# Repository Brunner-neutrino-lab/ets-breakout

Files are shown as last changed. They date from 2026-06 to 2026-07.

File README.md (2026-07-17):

# ETS per-channel SiPM breakout boards

Passive break-out boards that replace the (broken) **`iv-pulse-mux`** board in the
Brunner-lab **ETS-96-channel-IV-pulse-mux** system. Instead of relay-multiplexing 24
channels onto one shared sense line, each breakout board brings **every channel out to
its own coaxial jack** so channels can be biased/measured individually with external
instruments.

> Note: the public GitHub repo `IV-MUX-public` is a *different, older* board (15
> ch/board relay mux). The authoritative source is the read-only upstream snapshot
> under [`reference/ETS-96-channel-IV-pulse-mux/`](reference/) (`iv-pulse-mux`,
> connector **J5**) — see [`reference/UPSTREAM.md`](reference/UPSTREAM.md).

## What each board does

- Mates the detector-side connector **`QSE-040-01-L-D-A`** (J5) — same socket the
  `iv-pulse-mux` board used, mating the existing QTE-040 header upstream. **J5 sits on
  the back face (B.Cu)**, opposite the jacks: the detector plugs into the back, cables
  come off the front.
- Fans **25 signals → 25 coax jacks**: `SIPM_K0…K23` (24) + `IV` (1).
  `IV` is bussed on QSE pins 40 & 42 → one jack. `THERM4/THERM5` are **not** broken out.
  The detector socket keeps designator **J5** (upstream mapping); the jacks are **J6…J30**
  (K0→J6 … K23→J29, IV→J30), and each jack carries its channel identity (`K0…K23`, `IV`) as a
  **silkscreen label**. Mounting-hole designators (MH…) are hidden on silk.
- `GNDA` (52 signal-row pins + 8 G-pads) forms the ground/shield; a **guard ring** per
  channel tied to `GNDA`. No bias-tee / ESD diode / DC block.

### Variants
| Board | Jacks |
|---|---|
| **A** | 25 × MCX (straight, vertical through-hole) |
| **B** | 25 × SMA |
| **C** | 25 × U.FL |
| **D** | 25 × SMP (vertical SMT, SMP-MSLD-PCS-20) |

One board services one QSE-040 (25 ch). The full 96-channel system uses **4 boards**;
all four connectors share the identical J5 pinout, so a single layout works in every
position.

## Design decisions (2026-06-16)

| Aspect | Decision |
|---|---|
| Mechanical | **Free-form standalone** — only the QSE-040 must mate; fresh outline + mounting, no size constraint |
| J5 mounting face | **Back (B.Cu)** — detector mates on the back, all coax jacks on the front |
| Jack mounting | **Edge / right-angle** — jacks at board edges, cables exit sideways |
| Signal integrity | **Controlled 50 Ω, 4-layer** (L1 sig / L2 GND / L3 GND / L4 sig) |
| Guard | Guard ring per channel → `GNDA` |

## Pinout = single source of truth

[`pinout.py`](pinout.py) holds the authoritative QSE-040 (J5) pin→net map, derived from
the upstream schematic netlist (`kicad-cli sch export netlist`), **not** hand-transcribed
from a screenshot. The generator imports it; never hand-place a channel. Re-export and
regenerate if the upstream board changes.

```
python pinout.py             # dump signal -> QSE pin map
python tests/test_pinout.py  # sanity + self-consistency checks
```

## Build pipeline

All `tools/*.py` run under KiCad's bundled interpreter
(`"C:/Program Files/KiCad/10.0/bin/python.exe"`).

```
# Board A (MCX, through-hole) — FreeRouting autoroute, ZERO signal vias:
tools/gen_board.py mcx                 # placement + nets + outline + holes (balanced ~12/13 split; SPLIT="planar" = old 8/16)
tools/finalize_board.py <pcb> setup    # 4-layer stackup + GND zones (no routes yet)
tools/export_dsn.py <pcb> B.Cu         # write Specctra .dsn for the router
#   -> FreeRouting v2.2.4 (java) autoroute -> .ses
tools/import_ses.py <pcb>              # pull the routed B.Cu tracks back in
tools/finalize_board.py <pcb> stitch   # GND stitching vias
tools/fill_zones.py <pcb>              # fill GND pours (separate pass)
tools/tie_islands.py <pcb>             # island-tie vias
kicad-cli pcb drc <pcb>                # verify (0 violations, 0 unconnected)

# Boards B/C/D (SMA/U.FL/SMP) — deterministic router, single finalize pass:
tools/gen_board.py [sma|ufl|smp]
tools/finalize_board.py <pcb>          # stackup + 50 ohm routes + GND zones + stitching (one pass)
tools/fill_zones.py <pcb>
kicad-cli pcb drc <pcb>

kicad-cli pcb export gerbers|drill|pos ... ; tools/make_bom.py <pcb> <csv>   # fab outputs
```

**Board A** routes as a **balanced ~12/13 planar fan on B.Cu** (engineer-reviewed). The 25
jacks are split 12 on the west edge / 13 on the east and **ordered by their QSE pin** so every
native channel escapes as a **straight line**: west = K8–K15 (native) + K16,K17 (wrapping the
top corner) + K6,K7 (wrapping the bottom corner); east = K18–K23, IV, K0–K5. The 4 spilled
channels **wrap around the connector ends on B.Cu** (2 per corner), so the fan stays **all-B.Cu
with zero connector crossings and zero signal vias** (the through-hole MCX signal pin is plated
through every layer, so the B.Cu escape lands on it with no face-change via). FreeRouting does
the autoroute; only GND stitching + island-tie vias remain. Balancing shrank the board 32 mm
(75 × 157 → **75.0 × 125.2 mm**). The old lopsided 8/16 fan is retained as the `gen_board`
`SPLIT="planar"` option; `SPLIT="balanced"` is the default. **Boards B/C/D** still use the
deterministic router — escape past the QSE pads → one straight diagonal to the jack → straight
into the signal pad between grounds — with a 12/12 split (the `SPLIT="balanced"` flag) that
crosses 4 channels on the bottom layer. Vertical jacks (U.FL, MCX, SMP) are auto-rotated so
their signal pad faces the QSE.

## Status

**All four boards route DRC-clean (0 violations, 0 unconnected)** at the 50 Ω trace
width on the JLCPCB **JLC04161H-7628** 4-layer 1.6 mm stackup. Board A carries **0 signal
vias** (GND stitching + island-tie vias only; all 25 nets on B.Cu).

| Board | Connector | Size | Fab package |
|---|---|---|---|
| A | MCX straight, through-hole (MCX-J-P-H-ST-TH1) | 75.0 × 125.2 mm | `boards/board-A-mcx/board-A-mcx-fab.zip` |
| B | SMA (901-143-6RFX) | 75 × 149 mm | `boards/board-B-sma/board-B-sma-fab.zip` |
| C | U.FL (U.FL-R-SMT-1) | 70 × 99 mm | `boards/board-C-ufl/board-C-ufl-fab.zip` |
| D | SMP (SMP-MSLD-PCS-20) | 75 × 120 mm | `boards/board-D-smp/board-D-smp-fab.zip` |

Each fab zip = gerbers (4 copper + mask/silk/edge) + Excellon drill + position CSV + BOM CSV.

**Assembly:** the default build is **fab-only + hand-solder** (exact Samtec parts from
DigiKey). An optional **JLCPCB assembled build is possible** as a mixed SMT (QSE) + THT (MCX)
job using LCSC parts: QSE-040 = **C3652741** (exact Samtec, plain -A), MCX = **C5137197**
(BAT Wireless `BWMCX-KE`, a generic 50 Ω THT MCX jack; alt **C49118404**). Both are JLC-library
*Extended* parts and the 25 THT MCX jacks need JLC's through-hole/wave-solder assembly add-on.
**Gate before an assembled order:** confirm the `BWMCX-KE` land pattern matches our footprint
(centre signal + 4 grounds on 5.08 mm, drills 1.10/1.40) — it's a generic equivalent, not
dimensionally verified. The fab BOM (`make_bom.py`) carries these in an **LCSC column**. Fab is
**JLCPCB only**.

**Impedance:** channel traces are **0.325 mm** wide (unchanged) ≈ 50 Ω single-ended microstrip
on the JLCPCB **JLC04161H-7628** 4-layer 1.6 mm stack (0.2104 mm 7628 prepreg to the adjacent
inner GND plane, Dk ≈ 4.4), GND pour held back 0.30 mm to limit coplanar coupling. 0.325 mm is
JLC's own published 50 Ω single-ended width for JLC04161H-7628; the full derivation (JLCPCB
calculator RS_50 = 0.3244 mm + KiCad TransLine / IPC-2141 microstrip, every input stated) is in
[`docs/impedance.md`](docs/impedance.md). **Order as controlled impedance** (JLC's
impedance-control option on that stackup) so JLC re-tunes the etched width to their exact stackup.

**Footprints — all datasheet-verified:** MCX `Samtec_MCX-J-P-H-ST-TH1` (straight, vertical
**through-hole** jack) matches the Samtec drawing (`docs/datasheets/`, mcx-j-p-x-st-th1-mkt):
pad 1 signal drill Ø1.10 mm centered + 4× ground drill Ø1.40 mm on a 5.08 mm square. SMA and
U.FL from the KiCad library; QSE-040 from the ETS repo; SMP `SMP_Amphenol_SMP-MSLD-PCS-20`
(Amphenol RF, vertical SMT) is the SnapMagic land pattern (pad `G` renamed to `2`), signal on
an external tab.

**3D models:** QSE-040 and SMP have local STEP models in [`models/`](models/); U.FL uses
KiCad's bundled model. SMA and the through-hole MCX have no 3D model yet (gap). Models are
visual only — fab is unaffected.

**Before committing to fab:**
- Boards are built directly from `pinout.py` (no netlist-driven flow). A **reference
  schematic for human review** is in [`docs/schematic/`](docs/schematic/) (PDF + `.kicad_sch`),
  generated from the same `pinout.py` by `tools/gen_schematic.py` — its exported netlist is
  verified identical to the pin map.
- ~~Confirm the straight-MCX orderable MPN~~ **Confirmed 2026-07-15:** Board A is now
  **through-hole** — `MCX-J-P-H-ST-TH1` (DigiKey SAM8944-ND). Purchase package in [`order/`](order/).

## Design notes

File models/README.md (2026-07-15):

# 3D models

STEP models referenced by the footprints in [`../lib/ets-breakout.pretty/`](../lib/ets-breakout.pretty/).
Footprints reference these via `${KIPRJMOD}/../../models/<file>` — `KIPRJMOD` resolves
to each board's directory (`boards/board-*/`), so `../../models/` lands here regardless
of which board is open.

| Part | File | Source | Status |
|---|---|---|---|
| QSE-040-01-L-D-A (J5) | `QSE-040-01-L-D-A.stp` | upstream `reference/` snapshot | **present** |
| MCX-J-P-H-ST-TH1 (Board A, THT) | — | — | **gap** (need vertical through-hole model; the SMD `MCX-J-P-X-ST-SM1.step` no longer matches Board A's through-hole part) |
| SMP-MSLD-PCS-20 (Board D) | `SMP-MSLD-PCS-20.stp` | Amphenol / SnapMagic | **present** |
| U.FL-R-SMT-1 (Board C) | `U.FL_Hirose_U.FL-R-SMT-1_Vertical.step` | KiCad bundled lib (copied local) | **present** |
| SMA 901-143-6RFX (Board B) | — | — | **gap** (vendor-gated) |

Two footprints lack a local resolving model — **Board A MCX THT** and **SMA**.

- **MCX-J-P-H-ST-TH1** (Board A): Board A moved from the SMD MCX to the through-hole
  `MCX-J-P-H-ST-TH1`. The old `MCX-J-P-X-ST-SM1.step` is the SMD variant and no longer matches
  the through-hole part, so no model resolves for the `Samtec_MCX-J-P-H-ST-TH1` footprint. To
  fill it, source a vertical THT MCX STEP, drop it here, and add a
  `(model "${KIPRJMOD}/../../models/<file>")` line to
  `lib/ets-breakout.pretty/Samtec_MCX-J-P-H-ST-TH1.kicad_mod`.
- **SMA** (Board B): the SMA STEP is behind a vendor login (Amphenol RF / SnapMagic / Ultra
  Librarian); its footprint carries no `(model …)` line. To fill it, drop the vendor STEP here
  as `SMA_Amphenol_901-143-6RFX.stp` and add a
  `(model "${KIPRJMOD}/../../models/SMA_Amphenol_901-143-6RFX.stp")` line to
  `lib/ets-breakout.pretty/SMA_Amphenol_901-143_Horizontal.kicad_mod`, then regenerate Board B.

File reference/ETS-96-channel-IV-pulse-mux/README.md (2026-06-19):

# ETS 96-Channel IV-Pulse Multiplexer

**Organization:** McGill University Physics – Electronic Design Support Group  
**Designer:** Eamon Egan  
**Schematic Date:** 2019-11-12 (Rev 1.0)  
**Design Tool:** KiCad 9.0  

---

## Overview

This repository contains the complete design files for a **96-channel I-V curve pulse multiplexer** used in detector physics instrumentation. The system routes bias voltage and sense signals to one of 96 detector channels (e.g., SiPMs or similar devices) under Arduino microcontroller command, enabling automated current-voltage (I-V) characterization of large detector arrays.

The system is organized as:
- **Four 24-channel Mux boards** (`iv-pulse-mux`) — each handling 24 detector channels via reed relays and shift registers.
- **One Motherboard** (`iv-pulse-motherboard`) — orchestrating all four mux boards, distributing power, and providing the interface to the control system.
- **Arduino firmware** (`Arduino code/iv-mux/iv-mux.ino`) — running on an Arduino Nano Every (ATmega4809), accepting serial commands to switch channels, read temperature, and control auxiliary lines.

---

## Repository Layout

```
.
├── README.md                          ← This file
├── docs/                              ← Project documentation
│   ├── architecture.md                ← System-level design overview
│   ├── hardware/
│   │   ├── iv-pulse-mux-board.md      ← IV Pulse Mux PCB documentation
│   │   ├── motherboard.md             ← Motherboard documentation
│   │   ├── component-libraries.md     ← Custom schematic and footprint libraries
│   │   └── pcb-design-rules.md        ← Net classes and PCB design rules
│   ├── firmware/
│   │   ├── firmware-overview.md       ← Arduino firmware architecture
│   │   └── serial-commands.md         ← Serial command protocol reference
│   ├── fabrication/
│   │   └── fabrication-guide.md       ← Fabrication and assembly guide
│   └── operation/
│       └── user-guide.md              ← System operation and integration guide
│
├── Arduino code/iv-mux/iv-mux.ino    ← Microcontroller firmware
│
├── iv-pulse-mux.kicad_pro             ← KiCad project: IV Pulse Mux board
├── iv-pulse-mux.kicad_sch             ← Root schematic (IV Pulse Mux)
├── iv-pulse-mux.kicad_pcb             ← PCB layout (IV Pulse Mux)
│
├── iv-pulse-motherboard.kicad_pro     ← KiCad project: Motherboard
├── iv-pulse-motherboard.kicad_sch     ← Root schematic (Motherboard)
├── iv-pulse-motherboard.kicad_pcb     ← PCB layout (Motherboard)
│
├── Channels.kicad_sch                 ← Hierarchical sheet: 24 channel cells
├── sense-relay.kicad_sch              ← Hierarchical sheet: single sense relay cell
├── sense-relays.kicad_sch             ← Hierarchical sheet: sense relay group
├── bias-relay.kicad_sch               ← Hierarchical sheet: single bias relay cell
├── bias-relays-with-control.kicad_sch ← Hierarchical sheet: bias relay group
├── control.kicad_sch                  ← Hierarchical sheet: shift register control
├── muxboard-interface.kicad_sch       ← Hierarchical sheet: board connector interface
│
├── iv-mux.pretty/                     ← Custom PCB footprint library
├── samtec-footprints.pretty/          ← Samtec QSE connector footprints
├── passthrough.pretty/                ← Panel passthrough connector footprints
├── bias-switches-symlibs/             ← Custom schematic symbol library
│
├── fab-files.kicad_jobset             ← Automated fabrication output job set
├── fabrication-toolkit-options.json   ← Gerber export settings
├── fp-lib-table                       ← KiCad footprint library table
├── sym-lib-table                      ← KiCad symbol library table
└── mcgill-university-2.*              ← McGill University logo (SVG/DXF/PNG)
```

---

## Quick-Start

### Hardware

1. Order PCBs and assemble using the [Fabrication Guide](docs/fabrication/fabrication-guide.md).
2. Stack up to four Mux boards on the Motherboard via the Samtec QSE-040 connectors.
3. Connect detector channels to MCX connectors on the Mux boards.
4. Apply bias supply and sense lines via the Motherboard.

### Firmware

1. Open `Arduino code/iv-mux/iv-mux.ino` in the Arduino IDE.
2. Ensure `#define IVPULSEMUX` is present (enabled by default).
3. Select board: **Arduino Mega or Mega 2560** (required for ATmega4809 / Nano Every with Mega2560 profile).
4. Upload to the Arduino Nano Every.
5. Open a serial terminal at **9600 baud**.
6. Type a blank line to print the command help.

For a full command reference, see the [Serial Commands Reference](docs/firmware/serial-commands.md).

---

## Documentation Index

| Document | Description |
|---|---|
| [System Architecture](docs/architecture.md) | Top-level design intent, block diagram, and signal flow |
| [IV Pulse Mux Board](docs/hardware/iv-pulse-mux-board.md) | Schematic, PCB, and component details for the 24-channel mux board |
| [Motherboard](docs/hardware/motherboard.md) | Schematic and PCB details for the control motherboard |
| [Component Libraries](docs/hardware/component-libraries.md) | Custom schematic symbols and PCB footprints |
| [PCB Design Rules](docs/hardware/pcb-design-rules.md) | Net classes, clearances, and trace width rules |
| [Firmware Overview](docs/firmware/firmware-overview.md) | Arduino firmware architecture and state machine |
| [Serial Commands](docs/firmware/serial-commands.md) | Complete serial command protocol reference |
| [Fabrication Guide](docs/fabrication/fabrication-guide.md) | PCB fab, BOM, and assembly instructions |
| [User / Operation Guide](docs/operation/user-guide.md) | How to operate and integrate the system |

---

## Known Issues / Open Items (Rev 1.0)

- `BYPASS` signal is connected to Arduino pin 12 as a **temporary workaround**; the comment in firmware notes this should be corrected in a future revision.
- The `iv_on_pins[]` array uses analog pins `A0–A3` instead of the originally intended `THERM1–THERM4` thermistor pins — firmware comment notes this was an oversight.
- Low-power sleep mode (`LOWPOWER_SLEEP`) was prototyped but **is currently disabled**; register access issues on the ATmega4809 need to be resolved.
- The `q` (sequence) command is **only available in non-IV-pulse-mux mode** (i.e., the older 6×15 channel variant).
- Symbol library `iv-mux-rescue` references an absolute path on the designer's machine (`C:/Users/eamon/...`) and must be remapped when opening on a different workstation.

---

## Revision History

| Rev | Date | Description |
|---|---|---|
| 1.0 | 2019-11-12 | Initial release (schematic date) |

---

## License

Hardware design files are the property of McGill University Physics, Electronic Design Support Group. Contact the Brunner Neutrino Lab for use and distribution terms.

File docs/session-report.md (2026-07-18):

# Session handoff — ETS per-channel breakout boards

Report from the development session that built `ets-breakout/`. Intended for a
"manager" session reorganizing the whole working directory.

> **Historical record.** The reorganization this report recommended (§5–§6) has
> since been carried out: `ets-breakout/` is now its own standalone git repo, the
> upstream clone is a de-gitted read-only snapshot under `reference/`, and the SMP
> project is a separate sibling repo. Paths below describe the *old* layout.

> **Update 2026-06-22 — Board D (SMP) added.** A fourth variant was generated with
> the same pipeline: 25× **Amphenol SMP-MSSB-PCS** (SMP *male*, vertical SMT,
> 50 Ω DC–18 GHz), footprint carried over from the sibling SMP-feedthrough project.
> Unlike A/B/C, the SMP's center signal pad is enclosed by its ground frame on all
> four sides, so `finalize_board.py` routes the channel on B.Cu under the frame and
> enters through a **center via-in-pad** (gated on jacks whose footprint name
> contains "SMP"). Board is 74 × 112 mm, **DRC 0/0**, all 25 signal pads via-verified;
> fab package at `boards/board-D-smp/board-D-smp-fab.zip`. Fab note: order with
> plugged/capped vias (or hand-solder) so the SMT joint doesn't wick into the via.

> **Update 2026-06-22 — J5 moved to the back face (all boards).** The QSE-040 (J5)
> is now mounted on the **opposite PCB face from the coax jacks** (J5 on B.Cu, jacks
> on F.Cu): the detector plugs into the back, cables come off the front. `gen_board.py`
> flips J5 after assigning nets; the pad→net binding is preserved, so connectivity is
> unchanged. `finalize_board.py` was made face-agnostic — it detects which copper face
> J5's SMD pads are on (via `IsOnLayer`, since `GetLayer()` lies for a flipped SMD pad)
> and routes escapes on that HOME layer, hopping to the OTHER signal layer only for the
> crossing fans. All four boards re-routed and re-exported: **DRC 0/0**, J5 = bottom and
> all 25 jacks = top in the placement CSVs.

> **Update 2026-06-22 — 3D models + Board A changed to straight MCX.** 3D STEP models
> were attached: QSE-040 (from `reference/`), SMP-MSSB-PCS and the straight MCX (from the
> sibling SMP-feedthrough project) live in `models/` and are referenced via
> `${KIPRJMOD}/../../models/…`; U.FL uses KiCad's bundled model. SMA's 3D model was
> skipped. **Board A now uses a straight (vertical) surface-mount MCX jack**
> (`Samtec MCX-J-P-X-ST-SM1`, datasheet rev C) instead of the right-angle through-hole
> part — cable exits straight up, flat placement, and the signal pad routes like U.FL
> (SMD, signal reachable between the four corner grounds, no center via). The right-angle
> MCX footprint and its datasheet were removed. Boards A & B re-routed and re-exported,
> **DRC 0/0**. Straight-MCX orderable MPN (`MCX-J-P-H-ST-SM1`) is inferred — confirm.

## 1. What this session built

Three PCBs that **replace the broken `iv-pulse-mux` board** in the Brunner-lab
**ETS-96-channel-IV-pulse-mux** system with a *passive per-channel breakout*. Each
board mates the detector-side **QSE-040-01-L-D-A** socket and fans every channel out
to its own coax jack:

| Board | Jacks (25 each) | Part | Status |
|---|---|---|---|
| A | MCX × 25 | Samtec MCX-J-P-H-RA-TH1 (DK SAM10607-ND) | DRC 0/0, fab-ready |
| B | SMA × 25 | Amphenol RF 901-143-6RFX (DK ARFX1232-ND) | DRC 0/0, fab-ready |
| C | U.FL × 25 | Hirose U.FL-R-SMT-1(10) | DRC 0/0, fab-ready |

25 break-outs = 24 `SIPM_K0..K23` + `IV`. 12 K-channels bundle to flange 1 (one edge),
12 to flange 2 (other edge), IV to flange 3. 4-layer, 50 Ω microstrip on PCBWay default
4-layer stackup, GND pours all layers + stitching, 4× M3 holes. All footprints are
datasheet-verified.

**Everything is generated from one source of truth, `pinout.py`** — no hand placement.
Pipeline (KiCad 10 bundled Python):
```
gen_board.py [mcx|sma|ufl]   placement + nets + outline + holes  (imports pinout.py)
finalize_board.py <pcb>      4-layer stackup + 50Ω routes + GND zones + stitching
fill_zones.py <pcb>          fill pours (separate pass; in-memory fill segfaults)
kicad-cli pcb drc / export   verify + gerbers/drill/pos ; make_bom.py for BOM
```

## 2. Key decisions (with rationale)

- **Source repo identification.** The repo Lucas named (`ETS-96-channel-IV-pulse-mux`)
  is the right one; the public GitHub `IV-MUX-public` is a *different, older* board —
  don't conflate. The authoritative QSE-040 (J5) pin→net map was extracted from the
  upstream schematic **netlist** (`kicad-cli sch export netlist`), not eyeballed.
- **QSE-040 is carried on the new board** (same socket the mux used), mating the existing
  QTE-040 upstream. Confirmed with Lucas.
- **Flexible 12/12 channel→flange split** (Lucas's call). The connector's two pin rows
  are asymmetric (16 channels one row, 8 the other), so a 12/12 split has a hard floor of
  **4 nets crossing** the connector (routed on the bottom layer). The generator computes
  the optimal split from pad geometry to hit that floor.
- **Routing primitive = escape + single straight diagonal + straight into pad.** Monotonic
  fans are planar this way. (Vertical-bus and nested-bus fan-outs were tried and both
  introduced crossings — diagonal is correct here.)
- **IV jack** ended up inline on one edge (a center-top position had no clean routing
  lane). Still a separate connector cabled to flange 3.
- **Trace width 0.34 mm ≈ 50 Ω** microstrip on the PCBWay default 4-layer; `EDGE_GAP`
  widened to 26 mm so the end-channel fan diagonals stay shallow enough to clear at width.
  Recommend ordering as **controlled impedance** so PCBWay tunes to their exact stackup.
- **U.FL** = low-voltage use only (rated ~60 V vs bias up to ~70 V); noted, Lucas accepted.

## 3. Status / what's verified vs assumed

- All three boards: **0 DRC violations, 0 unconnected.** Fab packages
  (`boards/board-*/...-fab.zip`) = gerbers (4 copper + mask/silk/edge) + Excellon drill +
  placement CSV + BOM CSV.
- All four footprints datasheet-verified (MCX vs Samtec drawing rev H, archived in
  `docs/datasheets/`; SMA + U.FL from KiCad lib; QSE-040 from the ETS repo).
- **Open items (housekeeping, not blocking):** (a) no schematic/netlist — boards are built
  directly from `pinout.py`, which is unconventional; (b) MCX signal pin assumed centered
  in the ground square (drawing shows no offset); (c) impedance is nominal — confirm with
  PCBWay's stackup; (d) the `MCX-J-P-H-RA-TH1` 3D model isn't attached (cosmetic).

## 4. `ets-breakout/` layout (clean, self-contained)

```
ets-breakout/
  pinout.py                      SINGLE SOURCE OF TRUTH (QSE-040 J5 pin->net, breakout list)
  tests/test_pinout.py           sanity + self-consistency checks
  tools/  gen_board.py finalize_board.py fill_zones.py make_bom.py
  lib/ets-breakout.pretty/       4 verified footprints (QSE-040, MCX, SMA, U.FL)
  docs/datasheets/               Samtec MCX drawing rev H
  boards/board-{A-mcx,B-sma,C-ufl}/   .kicad_pcb/.kicad_pro + renders + *-fab.zip
  README.md                      full pipeline + status
```

## 5. The directory problem the manager should fix

The working dir currently mixes **three unrelated things** at the top level:

1. **The original SMP-feedthrough project** (different deliverable): `CLAUDE.md`,
   `smp-adapter-boards-brief.md`, `README.md`, `boards/`, `geometry/`, `lib/`, `tools/`,
   `tests/`, `docs/`, `models/`, `out/`, `MCX/`, and stray top-level reports
   (`board-A-mcx-drc.rpt`, `board-B-ufl-*.rpt/json`, `board-A-mcx-erc.rpt`).
2. **A clone of the upstream reference repo** `ETS-96-channel-IV-pulse-mux/` — **has its
   own nested `.git`** (messy inside the parent repo). It was the source of the pinout.
3. **This session's project** `ets-breakout/` (self-contained).

⚠️ **Name collision:** the SMP project's boards are *also* named `board-A-mcx` and
`board-B-ufl`; this project has `board-A-mcx`, `board-B-sma`, `board-C-ufl`. Two different
"board-A-mcx" exist. Keep them namespaced by project directory.

Other cruft to clean: `ets-breakout/__pycache__/`, `ets-breakout/board-*-drc.rpt` (kicad-cli
dumps to CWD), redundant renders in `board-A-mcx/` (`placement-A.svg`, `routed-A-*.pdf`,
keep `routed-top.pdf`). No `.gitignore` in `ets-breakout/`.

## 6. Recommended organization

- **Separate the two board projects into top-level directories** (or two repos):
  `smp-feedthrough/` (the original) and `ets-breakout/` (this one). They share *nothing*
  functionally and the name collision alone justifies the split. `ets-breakout/` is
  already self-contained and can move as-is.
- **The upstream `ETS-96-channel-IV-pulse-mux/` clone:** the data we needed is already
  captured (`ets-breakout/pinout.py` + archived datasheet). Recommend **removing its
  nested `.git`** and keeping it under `reference/` (read-only) *or* dropping it entirely
  and recording the upstream URL + commit in a README. Do **not** leave a nested git repo.
- **Add `.gitignore`** for `__pycache__/`, `*.kicad_prl`, stray `*-drc.rpt/json`,
  `out/`, and (decide) the generated `fab/` + renders since they regenerate from the tools.
- **Keep `ets-breakout/` as-is internally** — it follows the SMP project's own conventions
  (single-source-of-truth generator, local datasheet-verified footprints, test + DRC gate).
- Consider a **top-level README** that names the projects and points into each.

If the manager wants the boards rebuilt from scratch to confirm reproducibility:
`for v in mcx sma ufl: gen_board.py $v -> finalize_board.py -> fill_zones.py -> drc`.

> **Update 2026-06-24 — Board D SMP changed to SMP-MSLD-PCS-20.** Swapped the
> SMP-MSSB-PCS (enclosed centre pad) for **Amphenol RF SMP-MSLD-PCS-20** (vertical SMT,
> 4.08 mm max height), imported from the user-supplied SnapMagic footprint/symbol/STEP
> (pad `G` renamed `2`). Its signal is an **external tab** on one side of the body, so the
> centre via-in-pad scheme is gone — it routes like the other flat SMD jacks. `_edge` now
> rotates every flat jack so its signal pad faces the QSE, derived from the actual pad
> geometry (U.FL -X edge, SMP-MSLD +Y tab, MCX centred), replacing the hard-coded U.FL
> rotation; `finalize_board.py` dropped the SMP centre-via branch. Board D is 75 x 120 mm,
> **DRC 0/0**, all 25 tabs verified facing inward; all four boards re-checked 0/0.

> **Update 2026-07-11 — Board A finalized for purchase (MCX MPN confirmed, full order BOM).**
> The one open sourcing item is closed: **`MCX-J-P-H-ST-SM1` is the exact orderable straight-SMT
> MCX** (verified against the Samtec SM1 rev C drawing — now in `docs/datasheets/` as
> `Samtec_MCX-J-P-X-ST-SM1.pdf`; the previously-bundled `…ST-MT1.pdf` was the through-hole
> variant — and the live DigiKey listing **SAM10608-ND**, 4,577 in stock, $3.99 @ 100).
> QSE-040 socket confirmed as DigiKey **SAM8124-ND** ($7.27, 2,021 stk; plain suffix only —
> `-RT1` needs retention holes the board lacks). `make_bom.py` PARTS now carries both DK PNs;
> all four board BOM CSVs + fab zips regenerated. Board A re-verified: **0 DRC errors /
> 0 unconnected** (25 warning-level 0.7 mm silk text-height notes only, cosmetic).
> Controlled-impedance fab quotes pulled live: JLCPCB ~$65 HASL / ~$83 ENIG qty 5
> (JLC04161H-7628 stackup, ±5 Ω at 50 Ω, their 50 Ω width ≈0.35 mm vs our 0.34 mm nominal);
> PCBWay ~$122/$148. Full order table + DigiKey quick-add in `docs/BOM.md` §Purchase order.
> **System order ≈ $560–590** (110× MCX + 5× QSE + 5 PCBs, ENIG).

> **Update 2026-07-11 — MCX datasheet cleanup (MT1 drawing removed).** Re-verified
> `docs/datasheets/Samtec_MCX-J-P-X-ST-SM1.pdf` byte-identical (SHA-256) to the live
> Samtec print (`suddendocs.samtec.com/prints/mcx-j-p-x-st-sm1-mkt.pdf`); its text confirms
> *MCX STRAIGHT, SMT JACK – 50 OHM*, revision **C**, `-H` = heavy gold, tray packaging.
> Removed `Samtec_MCX-J-P-X-ST-MT1.pdf` (rev B, the mixed-technology/through-hole-leg MCX
> family — a different part not used on any board; keeping it invited exactly the
> SM1-vs-MT1 confusion it caused). The reference-only schematic symbol carried over from
> the SnapMagic MT1 import was renamed `MCX-J-P-X-ST-MT1` → `MCX-J-P-X-ST-SM1` (its
> Footprint field already pointed at the SM1 footprint), its Datasheet field repointed to
> the SM1 PDF, PARTREV B → C, and description filled in; `docs/BOM.csv` symbol column
> updated to match. `docs/datasheets/` is back to exactly the 5 per-part drawings
> CLAUDE.md advertises.

> **Update 2026-07-11 (later) — reference schematic for human review.** Added
> `tools/gen_schematic.py` → `docs/schematic/ets-breakout.kicad_sch` + `.pdf`: single A3
> sheet, J5 drawn as an 88-pin symbol whose **pin names are the nets themselves**, 25 jack
> symbols with the board's own refs (K0–K23, IV), all connectivity by net labels, THERM4/5
> no-connected. Generated from the same `pinout.py` the boards build from, so it cannot
> drift. Gates: **ERC 0 errors** (26 warning-level "lib nickname 'ets' not configured"
> notices are inherent to a standalone sheet with embedded symbols) and the sheet's exported
> netlist **machine-verified identical** to `pinout.py` (25 signal nets incl. IV on J5
> pins 40+42, GNDA 85/85 members, THERM4/5 unconnected). This is a review artifact only —
> the board pipeline is unchanged (still generated straight from `pinout.py`).

> **Update 2026-07-15 — Board A re-laid-out: through-hole MCX, 8/16 planar, FreeRouting autoroute, JLC stackup.**
> Board A was redone to eliminate the four connector-crossing traces the engineer flagged, and to
> retarget the design at JLCPCB. **Why the old tracks crossed:** the earlier layout forced a
> *balanced* **12/12** jacks-per-edge split (equal flange bundles), but the QSE-040's two pin rows
> are asymmetric (16 channels one row, 8 the other), so 12/12 has a hard floor of **4 nets crossing**
> the connector — routed on the other signal layer via 4 layer-hops. **The fix:** split the 24
> channels the way the connector already splits them — **8** on the west edge (K8–K15, the odd-pin
> row) and **16** on the east edge (K0–K7, K16–K23) **+ IV**, each jack placed on the edge matching
> its own QSE pin column. That gives a **monotonic single-layer fan on B.Cu with zero connector
> crossings**. (The old even split is retained only as a documented `SPLIT="balanced"` flag in
> `gen_board.py`.)
>
> **Jack changed SMD → through-hole:** Board A now uses **Samtec `MCX-J-P-H-ST-TH1`** (straight/
> vertical, through-hole, 50 Ω, 6 GHz female jack; DigiKey **SAM8944-ND**, $4.21 @ 100, ~11.6 k in
> stock; footprint `Samtec_MCX-J-P-H-ST-TH1`, pad 1 signal drill 1.10 mm centred, 4× ground drill
> 1.40 mm on a 5.08 mm square). A plated through-hole signal pin is copper on *all* layers, so the
> QSE's B.Cu channel escape lands directly on it with **no face-change via** — the whole board now
> has **zero signal vias** (only GND stitching + island-tie vias). This **reverses** the prior
> "confirmed MPN is the straight-SMD `MCX-J-P-H-ST-SM1` / SAM10608-ND" conclusion; that SMD part and
> its SM1 rev C drawing are no longer Board A's part. Right-angle THT `MCX-J-P-H-RA-TH1`
> (SAM10607-ND) is a valid mechanical alternative (side cable exit, needs a re-layout); do **not**
> cross to the 75 Ω `MCX7-J-P-H-ST-TH1` (SAM8945-ND) or the smaller `MMCX-J-P-H-ST-TH1`
> (SAM10617-ND). Assembly is now **mixed**: THT jacks are hand/selective-soldered, the QSE-040 stays SMD.
>
> **Impedance / fab:** trace width **0.325 mm** = 50 Ω single-ended microstrip on the **JLCPCB
> `JLC04161H-7628`** 4-layer 1.6 mm stack (0.2104 mm 7628 prepreg to the adjacent inner GND plane,
> Dk 4.4), GND-pour clearance 0.30 mm. Fab is **JLCPCB only** now (all PCBWay quotes/comparisons
> dropped); order as controlled impedance so JLC re-tunes the etched width. Board grew to
> **75.0 × 157.2 mm** (was 76 × 139; the east edge carries 17 jacks) — still 118 cm², under JLC's
> 650 cm² large-board surcharge. **DRC 0 violations / 0 unconnected**, all 25 nets on B.Cu.
>
> **Router + pipeline:** Board A now autoroutes with **FreeRouting** (KiCad → Specctra `.dsn` →
> FreeRouting v2.2.4 → `.ses` → KiCad), replacing the bespoke deterministic diagonal router (B/C/D
> still use the deterministic router). New Board A pipeline:
> `gen_board.py mcx` → `finalize_board.py <pcb> setup` → `export_dsn.py <pcb> B.Cu` → FreeRouting →
> `import_ses.py <pcb>` → `finalize_board.py <pcb> stitch` → `fill_zones.py <pcb>` →
> `tie_islands.py <pcb>` → `kicad-cli pcb drc`. New tool scripts: `tools/export_dsn.py`,
> `tools/import_ses.py`, `tools/tie_islands.py`; `finalize_board.py` gained `setup`/`stitch` modes.
> Unchanged: QSE socket `QSE-040-01-L-D-A` (SAM8124-ND), IV-out Cinch 3-0347-9 (1097-1372-ND), and
> `pinout.py` as the single source of truth.

> **Update 2026-07-17 — engineer review: balanced pin-ordered re-layout, J-designators, impedance doc, LCSC check.**
> An engineer review pass reworked Board A's layout, designators, and documentation without changing
> the electrical design, part, or fab vendor.
>
> **Why the old routes bundled/wrapped:** the previous **8/16 planar** split (from the 2026-07-15
> redo) was lopsided — the east edge carried 16 jacks + IV against 8 on the west, making the board
> long (75 × 157 mm) and leaving the FreeRouting autoroute to bundle escapes along the crowded edge.
> **The balanced fix:** the 24 channels are now split **~12/13** and, crucially, **each jack is
> ordered by its QSE pin** so every *native* escape is a **straight line**. West edge = **12 jacks**:
> K8–K15 (native, straight) + K16, K17 (wrap the top corner) + K6, K7 (wrap the bottom corner). East
> edge = **13 jacks**: K18–K23, IV, K0–K5. The 4 spilled channels **wrap around the connector ends on
> B.Cu (2 per corner)** rather than crossing the connector, so the design is still **zero signal vias,
> all 25 nets on B.Cu, DRC 0/0**. Balancing shrank the board 32 mm to **75.0 × 125.2 mm**. The old
> lopsided 8/16 is retained only as the `gen_board.py` `SPLIT="planar"` option; `SPLIT="balanced"` is
> now the default.
>
> **Designators K → J:** jack references were the channel names (K0..K23 / IV); those are relay
> designators (K = relay). Jacks are now proper connector references (**J**) — **J6..J30**
> (K0→J6 … K23→J29, IV→J30), while the detector socket keeps its upstream **J5**. The channel identity
> (K0..K23, IV) is now a **silkscreen label** printed next to each jack, and the mounting-hole
> designators (MH1..) are **hidden on silk**.
>
> **Impedance derivation documented:** trace width is **unchanged at 0.325 mm**, but a full derivation
> now lives in **`docs/impedance.md`** — JLCPCB calculator RS_50 = 0.3244 mm plus the KiCad TransLine /
> IPC-2141 microstrip formula, every input stated. 0.325 mm is JLC's own published 50 Ω single-ended
> width for the `JLC04161H-7628` stackup; order as controlled impedance.
>
> **LCSC / assembly:** default build is **fab-only + hand-solder** (exact Samtec parts from DigiKey).
> An optional **JLCPCB assembled build is viable** as a mixed SMT(QSE)+THT(MCX) job — LCSC PNs
> supplied by Lucas and vetted 2026-07-17: QSE-040 = **C3652741** (exact Samtec plain -A), MCX =
> **C5137197** (BAT Wireless `BWMCX-KE`, a generic 50 Ω THT MCX jack; deepest stock; alt
> `C49118404`; `C20415820` weakest). Both are JLC-library *Extended* parts and the 25 THT jacks
> need JLC's through-hole assembly add-on. **Gate:** the `BWMCX-KE` land pattern wasn't
> dimensionally verified against our footprint (centre signal + 4 grounds, 5.08 mm, 1.10/1.40
> drills) — confirm before an assembled order, else hand-solder the Samtec part. (Earlier this
> session an LCSC search wrongly concluded no MCX existed; Lucas's C-numbers corrected that.) A
> new **LCSC** column in the fab BOM carries MCX `C5137197` + QSE `C3652741`; the Cinch cable
> adapter = n/a (not board-mounted). **Unchanged:** the THT part (Samtec
> `MCX-J-P-H-ST-TH1` / DigiKey SAM8944-ND), footprint `Samtec_MCX-J-P-H-ST-TH1`, JLCPCB-only fab,
> quantities (MCX 120, QSE 5, IV adapter 4), DigiKey subtotal $831.19, system ≈ $950, QSE = SAM8124-ND,
> IV adapter Cinch 3-0347-9 / 1097-1372-ND, and `pinout.py` as the single source of truth.

> **Update 2026-07-18 — engineer's routing/placement cleanup + generator reproduces it.**
> The engineer opened Board A in the KiCad GUI, cleaned up the routing, and adjusted the MCX
> placement (commit `697d0fa`), but did not regenerate the fab. Reviewed: the only placement
> change was **swapping each wrap pair** — top corner K17↔K16 (J23/J22), bottom corner K7↔K6
> (J13/J12) — so the two arcs per corner nest without crossing; re-routed to 101 tracks, still
> **0 signal vias, all B.Cu, DRC 0/0**, 75×125 mm, netclass width 0.325 intact (GUI did not
> flatten the `.kicad_pro`). **Fab regenerated from the engineer's board** (gerbers/drill/pos/
> BOM/zips) so it matches what ships — his board is preserved byte-for-byte. **`gen_board.py`
> updated to reproduce the swap**: the wrapped (spilled) channels are now placed in *reversed*
> pin order (wrapping a corner reverses the fan sense), which regenerates his exact placement
> (verified: all 4 wrapped jacks land at identical coordinates) and FreeRouting on it yields an
> equivalent clean board (DRC 0/0, 0 vias). So the single-source-of-truth pipeline reproduces
> the engineer's design; the committed `.kicad_pcb` remains his hand-finished version.

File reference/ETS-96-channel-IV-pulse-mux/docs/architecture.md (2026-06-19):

# System Architecture

## Purpose

The ETS 96-Channel IV-Pulse Multiplexer is a relay-switched signal routing system designed to sequentially (or selectively) connect a single bias source and sense measurement instrument to one of **96 detector channels**. The primary use case is automated I-V (current-voltage) curve characterization of large detector arrays, such as Silicon Photomultipliers (SiPMs) or similar solid-state photodetectors used in particle physics experiments.

---

## System Block Diagram

```
                         ┌───────────────────────────────────────────┐
                         │             Motherboard                   │
                         │                                           │
  Serial (9600 baud) ────┤  Arduino Nano Every (ATmega4809)          │
  (USB or TTL UART)      │  ┌──────────────────────────────────┐     │
                         │  │  Firmware (iv-mux.ino)           │     │
                         │  │  - Command parser                │     │
                         │  │  - Relay state machine           │     │
                         │  │  - Shift register driver         │     │
                         │  └────────┬─────────────────────────┘     │
                         │           │  SPI-like shift reg. bus       │
                         │           │  (SRCLK, RCLK, SER0–SER3)     │
                         └───────────┼───────────────────────────────┘
                                     │
                    ┌────────────────┼────────────────────────────────┐
                    │                │  QSE-040 board-to-board connector│
                    │    ┌───────────▼──────────────────┐             │
                    │    │      IV Pulse Mux Board 1     │  Channels   │
                    │    │   24 channels (CH1–CH24)      │  1–24  ─────┼──► MCX connectors
                    │    │   MIC5891 shift register      │             │
                    │    │   Reed relays (bias + sense)  │             │
                    │    └──────────────────────────────┘             │
                    │    ┌──────────────────────────────┐             │
                    │    │      IV Pulse Mux Board 2     │  Channels   │
                    │    │   24 channels (CH25–CH48)     │  25–48 ─────┼──► MCX connectors
                    │    └──────────────────────────────┘             │
                    │    ┌──────────────────────────────┐             │
                    │    │      IV Pulse Mux Board 3     │  Channels   │
                    │    │   24 channels (CH49–CH72)     │  49–72 ─────┼──► MCX connectors
                    │    └──────────────────────────────┘             │
                    │    ┌──────────────────────────────┐             │
                    │    │      IV Pulse Mux Board 4     │  Channels   │
                    │    │   24 channels (CH73–CH96)     │  73–96 ─────┼──► MCX connectors
                    │    └──────────────────────────────┘             │
                    │                                                  │
                    │    Common bias supply ────────────────────────► │
                    │    Common sense line  ◄────────────────────────  │
                    │    (routed through selected relay on active board)│
                    └──────────────────────────────────────────────────┘
```

---

## Design Partitioning

### Why Split Into Two Board Types?

| Concern | Solution |
|---|---|
| 96 channels is too large for a single PCB at acceptable density | Split into four identical 24-channel mux boards |
| Centralized control logic and power distribution | Dedicated motherboard with Arduino and bus connections |
| Modularity and replaceability | Standardized QSE-040 connector allows any mux board to be swapped |

### Channel Numbering

Channels are numbered **1 to 96** in firmware. The mapping to boards is:

| Channel Range | Mux Board | Arduino SER Pin |
|---|---|---|
| 1 – 24 | Board 0 | Pin 2 |
| 25 – 48 | Board 1 | Pin 3 |
| 49 – 72 | Board 2 | Pin 4 |
| 73 – 96 | Board 3 | Pin 5 |

---

## Signal Paths

Each channel has two independent relay-switched paths:

### Bias Path (Reed Relay — "Bias Relay")
- Connects the shared **bias voltage rail** to the selected detector channel.
- Controlled by a bit in the MIC5891 shift register output (bits 0–23 per board).
- Relay coil is driven via shift register output pin.

### Sense Path (PhotoMOS Relay — "IV_ON")
- Connects the shared **sense/measurement line** to the selected detector channel's sense node.
- Controlled by `iv_on_pins[board]` (Arduino analog output pins A0–A3).
- One sense relay per board — only one channel per board can be sensed at a time (this is sufficient because only one channel per board is activated at a time).

### Bypass Line
- A separate signal path that can be enabled (pin `BYPASS`, Arduino pin 12) to route around the relay matrix for calibration or diagnostic purposes.
- Flagged as a temporary routing workaround in firmware Rev 1.0.

---

## Shift Register Architecture

Each mux board contains one **MIC5891** 8-bit latched serial-in, parallel-out power shift register. Multiple MIC5891 devices may be chained to achieve the 24-bit output width per board.

```
Arduino ──SRCLK──────────┬──────────────────────────────────────────►
         RCLK  ──────────┤──────────────────────────────────────────►
                         │
         SER0 ──────► [MIC5891 Board 0, 24 bits] ──► relay coils
         SER1 ──────► [MIC5891 Board 1, 24 bits] ──► relay coils
         SER2 ──────► [MIC5891 Board 2, 24 bits] ──► relay coils
         SER3 ──────► [MIC5891 Board 3, 24 bits] ──► relay coils
```

- All four boards share the same `SRCLK` and `RCLK` lines.
- Each board has a dedicated `SER` (serial data) line, enabling simultaneous parallel loading.
- Data is clocked MSB-first (bit 23 first).
- The output enable (`OE`) is held high during initialization, then driven low to enable relay outputs only after all registers have been initialized.

---

## Control Interface

The Arduino Nano Every provides a **9600-baud UART** interface. Commands are single-character mnemonics followed by numeric arguments, terminated by `\n` or `\r`.

Key operations:
- **Activate a channel** (`a <ch>`) — closes bias and sense relays for one channel, opens all others.
- **Independent relay control** (`b`, `s`) — set individual relay states for calibration or diagnostic use.
- **Bypass control** (`y`/`Y`) — activate/deactivate the bypass signal line.
- **Temperature monitoring** (`t`) — read ATmega4809 internal die temperature in Kelvin.
- **State dump** (`d`) — print current relay state as hex words.

See [Serial Commands Reference](../firmware/serial-commands.md) for the complete protocol.

---

## Synchronization

A dedicated **sync pulse input** is provided on Arduino pin 8 (`SYNC_PULSE`). This is used in the sequence (`q`) command (non-pulse-mux variant) to synchronize channel switching to an external trigger (e.g., a falling-edge voltage transition from a measurement instrument).

In the IV-pulse-mux variant, the `q` command is disabled; triggering is expected to be handled externally.

---

## Operating Modes

The firmware supports two hardware variants via a compile-time flag:

| Mode | `#define` | Boards | Channels/Board | Total |
|---|---|---|---|---|
| IV Mux (legacy) | *(undefined)* | 6 | 15 | 90 |
| IV Pulse Mux (current) | `IVPULSEMUX` | 4 | 24 | 96 |

The PCB described in this repository is the **IV Pulse Mux** variant. The IV Mux variant used a 74HC595 shift register and a different sense relay scheme; its support remains in the firmware for backward compatibility.

---

## Design Considerations for Future Revisions

1. **BYPASS pin assignment** should be moved from the temporary pin 12 to a dedicated pin.
2. **Thermistor inputs** (`THERM1–THERM4`) should be correctly wired if thermal monitoring is desired; `iv_on_pins[]` currently occupies `A0–A3`.
3. **Low-power sleep mode** should be revisited using ATmega4809-specific register definitions.
4. **Symbol library path** for `iv-mux-rescue` is currently an absolute Windows path; migrate to a relative project path.
5. **Sequence command** (`q`) support for the IV-pulse-mux variant should be evaluated for future addition.

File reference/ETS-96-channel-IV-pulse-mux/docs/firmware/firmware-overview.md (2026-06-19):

# Firmware Overview

**File:** `Arduino code/iv-mux/iv-mux.ino`  
**Target Hardware:** Arduino Nano Every (ATmega4809)  
**Arduino Board Profile:** Mega 2560 (required for Nano Every in this configuration)  
**Baud Rate:** 9600 bps  

---

## Overview

The firmware provides a simple command-line interface over a serial UART connection to control the relay state of the ETS 96-Channel IV-Pulse Multiplexer. It:

- Accepts text commands over `Serial` (USB-to-UART on Arduino Nano Every).
- Maintains a software representation of the relay states in memory (`outState[]`).
- Serializes relay state to the MIC5891 shift registers via a bit-bang SPI-like protocol.
- Provides temperature readout via the ATmega4809 internal temperature sensor.
- Supports a bypass line control signal.

---

## Build Configuration

### Compile-Time Mode Selection

The firmware supports two hardware variants via a preprocessor flag:

```cpp
// When defined: IV-Pulse Mux (4 boards × 24 channels = 96 channels)
#define IVPULSEMUX

// When undefined: IV Mux (6 boards × 15 channels = 90 channels, legacy)
```

**The IV-Pulse Mux variant (`#define IVPULSEMUX`) is the current and intended build.**

The legacy IV Mux variant (undefined) uses 74HC595 shift registers and a different sense relay scheme. It is retained for backward compatibility but should not be used with the current PCB hardware.

### Key Constants (IV-Pulse Mux Mode)

```cpp
const int boardCount       = 4;    // four mux boards
const int channelsPerBoard = 24;   // 24 relay channels per board
const int maxChan          = 96;   // total channel count

int serPins[4]      = { 2, 3, 4, 5 };      // SER0–SER3 data lines
int iv_on_pins[4]   = { A0, A1, A2, A3 };  // sense relay enables

const int SRCLK    = 9;   // shift register serial clock
const int RCLK     = 10;  // shift register latch (output register strobe)
const int SRCLR    = 11;  // asynchronous clear (active low) [assigned to OE in IVPULSEMUX]
const int OE       = 11;  // output enable (active low) [IVPULSEMUX only]
const int BYPASS   = 12;  // bypass signal [temporary pin assignment]
const int SYNC_PULSE = 8; // external sync/trigger input
```

---

## Relay State Representation

The relay state is stored in a 32-bit word array:

```cpp
uint32_t outState[4];  // one word per mux board
```

Each word has **24 active bits** (bits 23–0), where each bit corresponds to a bias relay coil on that board:

- Bit 0 → Channel 1 on that board (e.g., global Channel 1 for Board 0)
- Bit 23 → Channel 24 on that board (e.g., global Channel 24 for Board 0)

The **sense relay** is not encoded in `outState`. Instead, it is controlled directly by driving `iv_on_pins[board]` HIGH or LOW.

---

## Shift Register Write Protocol

The `writeState()` function serializes `outState[]` to the MIC5891 shift registers using a bit-bang protocol:

```
For each of the 24 bits (MSB first, bit 23 down to bit 0):
    Set SER0–SER3 simultaneously (each board's bit for this position)
    Pulse SRCLK HIGH → LOW  (clock in the bit)

After all 24 bits:
    Pulse RCLK HIGH → LOW   (latch output registers → relay coils energized)
```

All four boards are loaded **simultaneously** in each SRCLK pulse, minimizing the time between the first board and last board activating their relays.

---

## Command Processing

The main loop polls for serial input one character at a time. When a newline (`\n` or `\r`) is received, the accumulated buffer is tokenized and dispatched to the appropriate command handler.

### State Machine

```
                  ┌─────────────────────────────────┐
                  │              loop()              │
                  │                                  │
  Serial input ──►│  Read char → append to inbuf    │
                  │                                  │
                  │  On '\n' or '\r':                │
                  │    tokenize(command, arg1, arg2) │
                  │    dispatch command              │
                  │    print status                  │
                  │    clear buffer                  │
                  └─────────────────────────────────┘
```

### Command Dispatch Table

| Command | Function Called | Side Effect |
|---|---|---|
| `a` | `channelActive(chan)` | Zeros state, sets bias+sense for one channel, writes to hardware |
| `b` | `setBiasRelayState(chan, state)` + `writeState()` | Updates bias relay bit and immediately writes |
| `s` | `setSenseRelayState(chan, state)` | Updates sense relay (IV_ON pin); does NOT auto-write in IV-pulse-mux mode |
| `w` | `writeState()` | Writes current `outState[]` to hardware |
| `z` | `zeroState()` + `writeState()` | Clears all relay states and writes |
| `d` | `dumpState()` | Prints `outState[]` as 4 hex words |
| `t` | `tempRead()` | Reads ATmega4809 internal ADC temp sensor, prints Kelvin until keypress |
| `Y` | `digitalWrite(BYPASS, HIGH)` | Activates bypass line |
| `y` | `digitalWrite(BYPASS, LOW)` | Deactivates bypass line |
| *(empty)* | `printHelp()` | Prints command summary |

---

## Initialization Sequence (`setup()`)

1. Start Serial at 9600 baud.
2. Configure GPIO pins (SER0–3, IV_ON0–3, SRCLK, RCLK, OE, BYPASS, SYNC_PULSE).
3. Set OE HIGH (disable outputs) while initializing.
4. Zero all relay states (`zeroState()`).
5. Write zero state to shift registers (`writeState()`).
6. Set OE LOW (enable outputs) — relays now active.

This sequence ensures no relay is accidentally energized during power-up.

---

## Temperature Sensor

The `tempRead()` function reads the **ATmega4809 internal temperature sensor** using the on-chip ADC:

- Uses the `TEMPSENSE` mux channel (`ADC0.MUXPOS = 0x1E`).
- Sets VREF to internal 1.1 V reference.
- Applies maximum initialization and sample delay for accuracy.
- Converts raw ADC value to Kelvin using calibration constants from the signature row:
  ```
  Temperature (K) = (ADC_result - SIGROW_TEMPSENSE1) × (SIGROW_TEMPSENSE0 / 256.0)
  ```
- Prints a reading every 1 second until any serial character is received.

> **Note:** The internal die temperature is useful for monitoring thermal environment inside a vacuum enclosure but will reflect self-heating from the MCU itself. It is not a substitute for a precision external temperature sensor.

---

## Synchronization Pulse (`SYNC_PULSE`, Pin 8)

The `SYNC_PULSE` input is provided for synchronizing channel switching to an external trigger signal (e.g., a falling-edge voltage pulse from a measurement instrument). This is used by the `sequence()` function in the non-IV-pulse-mux legacy mode:

- When `delay < 0` in the `q` command, the firmware waits for a negative-going pulse on pin 8 that is at least `MIN_PULSE = 500 µs` wide before advancing to the next channel.
- In IV-pulse-mux mode, this pin is reserved but the `q` command is not compiled in.

---

## Low-Power Sleep Mode (Disabled)

The firmware includes a dormant implementation of low-power sleep (`LOWPOWER_SLEEP 0`). The intent was to reduce heat dissipation when the system is deployed in a vacuum enclosure. The implementation was abandoned because:

- ATmega4809 sleep register access failed to compile under the Mega2560 profile used for Nano Every.
- The `SLEEP_MODE_IDLE` mode was targeted.

This should be revisited in a future firmware revision using ATmega4809-specific sleep APIs.

---

## Ctrl+C Abort

A `CTRL_C` (`0x03`) character received during a sequence operation aborts the active sequence loop. This is the only form of in-progress command abort available.

---

## Building and Uploading

1. Install the **Arduino IDE** (1.8.x or 2.x).
2. Open `Arduino code/iv-mux/iv-mux.ino`.
3. Under **Tools → Board**, select **Arduino Mega or Mega 2560**.
4. Confirm `#define IVPULSEMUX` is present.
5. Connect the Arduino Nano Every via USB.
6. Click **Upload**.
7. Open the **Serial Monitor** at 9600 baud, no line ending or newline, to test commands.

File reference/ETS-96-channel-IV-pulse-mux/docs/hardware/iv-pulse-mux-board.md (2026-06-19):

# IV Pulse Mux Board

**KiCad Project:** `iv-pulse-mux.kicad_pro`  
**Schematic:** `iv-pulse-mux.kicad_sch` (root) with multiple hierarchical sheets  
**PCB Layout:** `iv-pulse-mux.kicad_pcb`  
**Channels per Board:** 24  
**Number of Boards in System:** 4 (96 total channels)

---

## Purpose

The IV Pulse Mux board is the primary signal switching module in the system. Each board routes bias and sense signals to one of 24 detector channels. Four identical boards are stacked on the motherboard to achieve 96-channel coverage.

---

## Schematic Hierarchy

The schematic is organized as a hierarchical design in KiCad. The root sheet (`iv-pulse-mux.kicad_sch`) instantiates the following sub-sheets:

| Sheet File | Description |
|---|---|
| `Channels.kicad_sch` | Top-level grouping of 24 channel cells; instantiates sub-rows of `sense-relay` and `bias-relay` sheets |
| `sense-relay.kicad_sch` | Single-channel sense relay cell (PhotoMOS or reed) |
| `sense-relays.kicad_sch` | Group of sense relay cells forming one board row |
| `bias-relay.kicad_sch` | Single-channel bias relay cell (reed relay) |
| `bias-relays-with-control.kicad_sch` | Group of bias relay cells with shift register control logic |
| `control.kicad_sch` | Shift register (MIC5891) control circuitry |
| `muxboard-interface.kicad_sch` | Board-to-board connector interface (Samtec QSE-040) |

---

## Key Components

### MIC5891 Serial-In, Parallel-Out Shift Register
- **Function:** Receives 24-bit serial control data from the Arduino and drives reed relay coils.
- **Interface:** Serial data (SER), serial clock (SRCLK), register clock / latch (RCLK).
- **Output:** Active-high open-drain outputs with internal current limiting, suitable for direct relay coil drive.
- **Note:** Multiple MIC5891 devices may be daisy-chained to achieve the required 24-bit width.

### Reed Relays — Bias Path (Standex-Meder)
- **Function:** Switch the shared bias voltage rail to an individual detector channel.
- **Footprint:** `Relay_StandexMeder_DIP_HighProfile_SSmod` and `Relay_StandexMeder_HI` (custom, in `iv-mux.pretty`).
- **Type:** DIP, high-profile package for air gap clearance.
- **Drive:** Coil driven directly by MIC5891 output pin.

### PhotoMOS Relay — Sense Path
- **Function:** Connect the shared measurement/sense line to the active detector board.
- **Footprint:** `photomos` and `SOP-4_3.8x4.1mm_P2.54mm` (custom, in `iv-mux.pretty`).
- **Alternative footprint:** `TLP170J` (also available in `iv-mux.pretty`).
- **Drive:** Controlled by Arduino `iv_on_pins[]` (A0–A3), one per board.
- **Note:** One sense relay per board (not per channel), because only one channel per board is active at a time.

### Samtec QSE-040 Board-to-Board Connector
- **Function:** Mechanically and electrically connects each mux board to the motherboard.
- **Footprints:** `SAMTEC_QSE-040-01-X-D-A` (PCB), with alignment variants `_SAI`, `_SAI-L`, `_SAI-M` for stacking height compensation.
- **Pin count:** 40 pins (2×20), carries SPI-like control bus, power, and bias/sense signals.
- **3D model:** `QSE-040-01-L-D-A.stp` included in the footprint library.

### MCX Connectors — Channel Outputs
- **Function:** Individual coaxial connectors for each of the 24 channel outputs.
- **Variants used:**
  - `MCX_Vertical` — vertical mount (in `iv-mux.pretty`).
  - `MCX_Molex_73415-1060_Horizontal_1.6mm-PCB` — horizontal mount, PCB edge (in `passthrough.pretty`).
  - `MCX_Molex_73415-1060_Horizontal_1.6mm-PCB_NOSILK` — same without silkscreen.
- **Purpose:** Connects individual detector device under test (DUT) cables.

---

## Signal Description

| Signal Name | Direction | Description |
|---|---|---|
| `BIAS_IN` | Input | Shared bias voltage from bias supply |
| `SENSE_IN` | Bidirectional | Shared sense/measurement line |
| `CH[1..24]` | Output | Individual detector channel connections (MCX) |
| `SER` | Input | Serial data from Arduino (one per board) |
| `SRCLK` | Input | Shift register clock (shared across boards) |
| `RCLK` | Input | Latch clock (shared across boards) |
| `IV_ON` | Input | Sense relay enable (one per board, from Arduino A0–A3) |
| `OE_N` | Input | Output enable (active low); shared across all boards |
| `+5V`, `GND` | Power | Logic and relay coil supply |
| `+BIAS`, `BIAS_GND` | Power | High-voltage bias supply rails |

---

## PCB Design

### Layer Stack
The `iv-pulse-mux.kicad_pcb` design uses a multi-layer stack (up to 31 copper layers as configured in the design rules, though the actual fabricated layer count should be confirmed from the Gerber outputs). See [PCB Design Rules](pcb-design-rules.md) for the full net class assignments.

### Net Classes (Summary)

| Net Class | Typical Traces | Track Width |
|---|---|---|
| `Default` | Control signals, low-current | 0.2032 mm |
| `power` | `+5V`, `GND`, `+BIAS` | 0.508 mm |
| `guard` | Guard ring traces | 0.4064 mm |
| `zcontrol` | SiPM signal traces, RF signals | 0.33528 mm |

### Hierarchical PCB

The file `iv-pulse-mux.kicad_pcb.hierpcb.json` indicates use of KiCad's hierarchical PCB feature, allowing the repeated 24-channel layout to be managed efficiently.

### Custom Footprints

All project-specific footprints are contained in the `iv-mux.pretty/` library. See [Component Libraries](component-libraries.md) for details.

---

## Board Dimensions and Connector Placement

> **Note:** Exact board dimensions and connector coordinates are defined in `iv-pulse-mux.kicad_pcb`. This document describes the design intent; the PCB file is the authoritative source for mechanical dimensions.

- Board edge cut outline is defined in the PCB file.
- Mounting holes use `MountingHole_2.1mm` footprint (in `passthrough.pretty`).
- `Gripping_hole_unplated` (in `passthrough.pretty`) provides mechanical strain relief.
- The McGill University logo appears on the silkscreen (imported from `mcgill-university-2.dxf`/`.svg`).

---

## Known Issues (Rev 1.0)

| Issue | Location | Impact |
|---|---|---|
| `BYPASS` signal connected to Arduino pin 12 (temporary) | Firmware + PCB | Signal routing workaround; should be assigned a dedicated pin |
| `iv_on_pins[]` uses `A0–A3` instead of intended `THERM1–THERM4` | Firmware | Thermistor monitoring not available on those pins |
| `iv-mux-rescue` symbol library references absolute path | `sym-lib-table` | Must be remapped on any new workstation |

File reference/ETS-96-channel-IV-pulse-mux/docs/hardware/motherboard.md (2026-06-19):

# Motherboard

**KiCad Project:** `iv-pulse-motherboard.kicad_pro`  
**Schematic:** `iv-pulse-motherboard.kicad_sch`  
**PCB Layout:** `iv-pulse-motherboard.kicad_pcb`

---

## Purpose

The motherboard is the central hub of the ETS 96-channel IV-Pulse Multiplexer system. It:

1. Hosts the **Arduino Nano Every** microcontroller.
2. Distributes the **SPI-like shift register control bus** (SRCLK, RCLK, SER0–SER3) to all four mux boards.
3. Routes the **sense relay enable signals** (IV_ON0–IV_ON3) to the mux boards.
4. Provides **power distribution** (5 V logic, bias voltage, and ground) to all mux boards via board-to-board connectors.
5. Accepts the **shared bias supply input** and the **shared sense/measurement line** from the measurement instrument.
6. Hosts all **QSE-040 board-to-board socket connectors** for the four mux boards.

---

## Schematic Hierarchy

The root schematic `iv-pulse-motherboard.kicad_sch` references the following sub-sheet:

| Sheet File | Description |
|---|---|
| `muxboard-interface.kicad_sch` | Interface circuitry for one mux board slot (instantiated 4 times) |

The motherboard uses the same `muxboard-interface.kicad_sch` hierarchical sheet as the mux board, which defines the 40-pin board-to-board connector pinout and any signal conditioning (level shifting, filtering, etc.) at the interface.

---

## Key Components

### Arduino Nano Every
- **MCU:** ATmega4809 (compiled under Mega2560 board profile)
- **Supply:** 5 V USB or external
- **Serial:** Connected to control PC via USB-to-UART or TTL UART on Serial1
- **GPIO usage:**

| Pin | Signal | Direction | Description |
|---|---|---|---|
| 2 | SER0 | Output | Serial data to Mux Board 0 |
| 3 | SER1 | Output | Serial data to Mux Board 1 |
| 4 | SER2 | Output | Serial data to Mux Board 2 |
| 5 | SER3 | Output | Serial data to Mux Board 3 |
| 8 | SYNC_PULSE | Input | External sync/trigger input (pull-up) |
| 9 | SRCLK | Output | Shift register serial clock |
| 10 | RCLK | Output | Shift register latch/strobe |
| 11 | OE_N / SRCLR | Output | Output enable (active low) |
| 12 | BYPASS | Output | Bypass line control (temporary assignment) |
| 13 | IV_ON (legacy) | — | Not used in IV-pulse-mux variant |
| A0 | IV_ON0 | Output | Sense relay enable, Board 0 |
| A1 | IV_ON1 | Output | Sense relay enable, Board 1 |
| A2 | IV_ON2 | Output | Sense relay enable, Board 2 |
| A3 | IV_ON3 | Output | Sense relay enable, Board 3 |

### QSE-040 Socket Connectors (×4)
- **Part:** Samtec QSE-040-01-X-D-A (socket side)
- **Mates with:** QSH-040 or equivalent header on each mux board
- **Purpose:** Carries all signals, power, and bias lines between motherboard and each mux board
- **Footprints:** `SAMTEC_QSE-040-01-X-D-A` in `samtec-footprints.pretty`

### Bias Supply Interface
- Provides the shared `BIAS_IN` rail to all mux boards via the QSE connector.
- The bias supply connection on the motherboard should include appropriate protection (TVS diode, fuse) — verify in the PCB schematic.

### Sense Line Interface
- Provides the shared `SENSE` line routed to all mux boards.
- Only the selected board's PhotoMOS relay connects this line to the active channel at any given time.

---

## Power Architecture

| Rail | Source | Distribution |
|---|---|---|
| +5 V | Arduino USB or external regulator | Provided to all QSE connectors; powers relay coils and logic on mux boards |
| GND | Common ground | All boards share a common ground reference |
| +BIAS | External bias supply input | Routed through motherboard to all QSE connectors; each mux board switches it per channel |
| BIAS_GND | Bias return (may be isolated) | Should be carefully considered for ground loop avoidance in high-impedance measurements |

> **Note:** The exact power topology (isolated vs. common ground, bulk capacitance, filtering) should be verified in the `iv-pulse-motherboard.kicad_sch` schematic. This document reflects design intent; the schematic is authoritative.

---

## Board-to-Board Mechanical Assembly

1. The four mux boards mount perpendicular or parallel to the motherboard via the Samtec QSE-040 connectors (stacking orientation depends on board outline design).
2. The QSE connector provides both the electrical interface and mechanical support.
3. Additional mechanical support (standoffs, gripping holes) may be present on both boards — see `passthrough.pretty/Gripping_hole_unplated.kicad_mod`.
4. Mounting holes use `MountingHole_2.1mm` from the `passthrough.pretty` library.

---

## External Connectors on Motherboard

| Connector | Type | Signal |
|---|---|---|
| Bias input | BNC or terminal block | External bias voltage supply (`BIAS_IN`, `BIAS_GND`) |
| Sense line | BNC or MCX | Shared measurement line to/from instrument |
| Arduino USB | Micro-USB (onboard Arduino) | Firmware programming and serial control |
| SYNC input | MCX or BNC | External trigger input for timed channel switching |
| BYPASS | MCX or test point | Bypass signal output |

> Exact connector types are defined in the PCB layout. Refer to `iv-pulse-motherboard.kicad_pcb` for authoritative placement.

---

## Known Issues (Rev 1.0)

| Issue | Details |
|---|---|
| BYPASS pin assignment | Pin 12 used as a temporary workaround; correct pin should be chosen in next revision |
| Thermistor inputs unused | A0–A3 occupied by IV_ON signals; thermistor monitoring deferred |
| Absolute symbol library path | `iv-mux-rescue` in `sym-lib-table` points to designer's local path; must be remapped |

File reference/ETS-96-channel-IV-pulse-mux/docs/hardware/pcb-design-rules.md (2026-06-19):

# PCB Design Rules

This document describes the net classes, trace widths, clearances, and design rule constraints used in the ETS 96-Channel IV-Pulse Mux PCB designs.

---

## Net Classes

Four net classes are defined in `iv-pulse-mux.kicad_pro`. These are used to automatically apply appropriate clearance and trace width rules based on signal type.

### Default
| Parameter | Value |
|---|---|
| Track width | 0.2032 mm (~8 mil) |
| Clearance | 0.2032 mm |
| Via diameter | 0.6 mm |
| Via drill | 0.3 mm |
| Microvia diameter | 0.3 mm |
| Microvia drill | 0.1 mm |

Used for: standard digital control signals, low-current signal traces.

---

### `power`
| Parameter | Value |
|---|---|
| Track width | 0.508 mm (~20 mil) |
| Clearance | 0.2032 mm |
| Via diameter | 0.6 mm |
| Via drill | 0.3 mm |

Used for: `+5V`, `GND`, bias voltage supply rails (`+BIAS`, `BIAS_GND`). Wider traces reduce resistive voltage drop and improve current handling.

---

### `guard`
| Parameter | Value |
|---|---|
| Track width | 0.4064 mm (~16 mil) |
| Clearance | 0.1524 mm (6 mil) |

Used for: guard ring traces surrounding sensitive analog nodes. Tighter clearance allows guard rings to closely surround signal pads while the wider track provides a low-impedance driven shield.

> **Guard ring purpose:** In high-impedance or low-current measurements (e.g., SiPM leakage current), guard rings driven at the same potential as the signal conductor prevent leakage currents across PCB surface from reaching the measurement node. This is critical for accurate pA–nA-level current measurements.

---

### `zcontrol`
| Parameter | Value |
|---|---|
| Track width | 0.33528 mm (~13 mil) |
| Clearance | 0.2032 mm |
| Via diameter | 0.6 mm |
| Via drill | 0.3 mm |

Used for: SiPM signal traces and RF signal paths. The `z` prefix and the net class pattern assignment (`*SIPM*`, `*RF*`) indicate that any net whose name matches `*SIPM*` or `*RF*` is automatically assigned to this class.

**Net class pattern rules (from project file):**
```
Pattern: *SIPM*  → netclass: zcontrol
Pattern: *RF*    → netclass: zcontrol
```

---

## PCB Design Rule Check (DRC) Severities

The following DRC rules are configured as **errors** (will block fabrication submission):

- Annular width violations
- Clearance violations
- Copper-to-edge clearance
- Courtyard overlaps
- Creepage distance violations
- Drill out of range
- Footprint errors
- Hole clearance / hole-to-hole / hole-near-hole
- Invalid board outline
- Items on disabled layers
- Microvia drill out of range
- Track length out of range

The following are **warnings** (reported but do not block):
- Connection width
- Copper slivers
- Duplicate footprints
- Extra footprints / missing footprints
- Footprint/symbol mismatch
- Isolated copper

The following are **ignored**:
- Missing courtyard
- Footprint type mismatch
- NPTH inside courtyard

---

## Default PCB Text and Drawing Sizes

| Property | Value |
|---|---|
| Board outline line width | 0.05 mm |
| Copper text size (H/V) | 1.5 mm × 1.5 mm |
| Copper text thickness | 0.3 mm |
| Silkscreen text size (H/V) | 1.0 mm × 1.0 mm |
| Silkscreen text thickness | 0.1 mm |
| Fab layer text size (H/V) | 5.0 mm × 5.0 mm |
| Courtyard line width | 0.05 mm |
| Fab layer line width | 0.1 mm |
| Other line width | 0.3 mm |

---

## Default Pad Dimensions

| Parameter | Value |
|---|---|
| Drill diameter | 0.762 mm |
| Pad height | 1.524 mm |
| Pad width | 1.524 mm |

---

## Fabrication Output Configuration

The `fab-files.kicad_jobset` automates production of:

| Output | Destination |
|---|---|
| Gerber files (all active layers) | `pcbfab/gerber/` |
| Drill files | `pcbfab/drill/` |
| BOM (CSV) | `assembly/iv-pulse-mux-bom.csv` |
| Component placement (CSV) | `assembly/iv-pulse-mux-positions.csv` |

Fabrication toolkit options (`fabrication-toolkit-options.json`):
- All active layers exported.
- Auto-translate enabled (coordinate origin correction).
- Auto-fill enabled.
- DNP (Do Not Populate) components excluded from assembly output.

> **Note:** Gerber output directories are listed in `.gitignore` and are **not committed to the repository**. They must be regenerated locally using the KiCad job set before board submission.

---

## Design Considerations for High-Impedance Measurements

The IV-pulse multiplexer is intended for precision low-current measurements. The following PCB practices are especially important:

1. **Guard rings** — Use the `guard` net class for guard traces around all high-impedance nodes (SiPM bias, sense lines, relay contacts).
2. **Surface leakage** — Use low-absorption PCB substrate (e.g., Rogers, PTFE, or at minimum FR4 with surface treatment) if measuring below ~1 nA.
3. **Relay contact protection** — Ensure no DC paths exist across relay contacts when open (relevant for reverse-biased detectors).
4. **Ground plane continuity** — Maintain continuous ground plane under signal layers to reduce noise coupling.
5. **Trace separation** — Sufficient spacing between bias rail and sense rail to prevent leakage at high bias voltages (creepage distance rule is enforced by DRC).

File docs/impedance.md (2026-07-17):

# Impedance control — ETS breakout Board A

How the **0.325 mm** channel trace width was derived, with every input parameter stated
and cross-checked against two independent tools (JLCPCB's calculator and the
KiCad TransLine / IPC-2141 microstrip formula). Order Board A **as controlled impedance**
on the JLCPCB **JLC04161H-7628** stackup so JLC re-tunes the etched width to their measured
stack.

Board A channel traces are a **single-ended microstrip** on an outer copper layer (B.Cu)
referenced to the **adjacent inner GND plane** through one 7628-prepreg dielectric, on the
JLCPCB 4-layer 1.6 mm **JLC04161H-7628** stackup. Target **Z₀ = 50 Ω**.

## (a) Stackup inputs (JLC04161H-7628, 1.6 mm, 4-layer)

| Parameter | Symbol | Value | Source / note |
|---|---|---|---|
| Outer copper (L1/L4), finished | t | **0.035 mm** (1 oz) | JLCPCB stackup page |
| Outer dielectric L1→L2 / L3→L4 (7628 prepreg ×1) | h | **0.2104 mm** | JLCPCB stackup page — the reference-plane distance |
| Prepreg 7628 dielectric constant | εr | **4.4** @ ~1 GHz | JLCPCB; Dk is frequency-dependent (glass-rich 7628 runs ~4.4–4.8) |
| Core (L2→L3) | — | **1.065 mm** | JLCPCB stackup page |
| Inner copper (L2/L3) | — | 0.0152 mm (0.5 oz) | JLCPCB stackup page |
| Soldermask over trace | — | ~1.2 mil (~0.013–0.019 mm over copper), Dk **3.8** | JLCPCB help |
| Target single-ended impedance | Z₀ | **50 Ω** | design |
| Trace-to-GND-pour clearance | — | 0.30 mm | matches JLC RS_50 clearance |

Total ≈ 0.035 + 0.2104 + 0.0152 + 1.065 + 0.0152 + 0.2104 + 0.035 ≈ 1.586 mm + mask ≈ 1.6 mm. ✓

## (b) JLCPCB impedance calculator

JLCPCB's own published 50 Ω single-ended routing structure for this exact stackup (JLC's
material library, mirrored in the JITX `JLC04161H_7628` module which encodes JLC's field
solver):

- **RS_50 (50 Ω single-ended, outer layer): trace width = 0.3244 mm, clearance 0.30 mm.**

Fields to reproduce in the live calculator (jlcpcb.com/pcb-impedance-calculator): Layers = **4**,
Board thickness = **1.6 mm**, Stackup = **JLC04161H-7628**, Impedance type = **Single-ended
(microstrip, outer layer)**, Target Z = **50 Ω**, Outer copper = **1 oz** → width ≈ **0.324–0.325 mm**.

**Design 0.325 mm vs JLC 0.3244 mm → within 0.2 %. Confirmed.**

## (c) KiCad TransLine / IPC-2141 microstrip formula

Closed-form IPC-2141 / Hammerstad–Jensen microstrip, inputs `h = 0.2104 mm, εr = 4.4,
t = 0.035 mm, Z₀ = 50 Ω`:

```
A   = (Z₀/60)·√((εr+1)/2) + ((εr−1)/(εr+1))·(0.23 + 0.11/εr)
W/h = 8·e^A / (e^{2A} − 2)                       (W/h < 2)
```

- Zero-thickness: A = 1.530, W/h = 1.912 → **W = 0.405 mm** (Z₀(0.405) = 50.4 Ω ✓).
- With 35 µm copper (what KiCad TransLine models): ΔW = (t/π)(1 + ln(2h/t)) = 0.039 mm →
  **W ≈ 0.367 mm** bare (no soldermask).

**KiCad → Calculator Tools → TransLine → Microstrip**, enter Er = **4.4**, H = **0.2104 mm**,
T = **0.035 mm**, Z0 = **50 Ω**, Freq ≈ **1 GHz** → width ≈ **0.36–0.37 mm** (KiCad models copper
thickness but not soldermask, so it reads wider than JLC's field solver).

**Reconciling the two:** the bare closed form gives ~0.367 mm; JLC's field solver gives
0.3244 mm — ~11 % narrower. The gap is real and expected, from three effects the bare formula
omits, all pushing narrower: (1) **soldermask loading** (Dk 3.8 raises εeff), (2) **effective
7628 Dk ≈ 5.0** > the 4.4 nominal (glass-rich prepreg + frequency), (3) JLC's **2-D field
solver** vs a closed-form approximation. Together they land on ~0.325 mm.

## (d) Conclusion

**0.325 mm is correct** — JLC's own published RS_50 width for the JLC04161H-7628 outer layer,
bracketed by the microstrip formula (0.405 → 0.367 → ~0.325 mm as copper thickness, soldermask
and true 7628 Dk are folded in). JLC controlled-impedance tolerance is **±10 %** (≈ ±0.032 mm),
and ordering **as controlled impedance** lets JLC re-tune the etched width to their measured
stack to hit 50 Ω — the drawn 0.325 mm only seeds that tuning.

*Sources: jlcpcb.com/impedance, /pcb-impedance-calculator; JLCPCB layer-stackup + soldermask
help; JITX `jitxlib.jlcpcb.JLC04161H_7628` (RS_50 = 0.3244 mm). Live calculator/KiCad-GUI reads
were not automated; formula values were computed numerically. Verified 2026-07-17.*
</content>

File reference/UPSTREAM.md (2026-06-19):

# Upstream reference — ETS-96-channel-IV-pulse-mux

`ETS-96-channel-IV-pulse-mux/` is a **read-only snapshot** of the Brunner-lab
multiplexer project. It is the source from which the authoritative QSE-040 (J5)
pin → net map in [`../pinout.py`](../pinout.py) was extracted (via
`kicad-cli sch export netlist`, not hand-transcribed). It is kept here for
provenance only — **do not edit it; do not build from it.**

| | |
|---|---|
| Origin | <https://github.com/Brunner-neutrino-lab/ETS-96-channel-IV-pulse-mux.git> |
| Commit | `757c28fd36a7ed9862af2c0177549747f3e05412` (`757c28f`) |
| Board / connector of interest | `iv-pulse-mux` board, connector **J5** (QSE-040-01-L-D-A) |

The clone's own `.git` was removed during the repo reorganization so this does
not nest a second git repository inside `ets-breakout`. To refresh the snapshot,
re-clone from the URL above at the desired commit.

> Note: the public GitHub repo `IV-MUX-public` is a *different, older* board
> (15 ch/board relay mux) — do not conflate it with this one.

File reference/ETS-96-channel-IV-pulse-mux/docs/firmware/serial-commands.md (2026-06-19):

# Serial Command Reference

## Connection Parameters

| Parameter | Value |
|---|---|
| Baud rate | 9600 bps |
| Data bits | 8 |
| Parity | None |
| Stop bits | 1 |
| Flow control | None |
| Line ending | `\n` or `\r` (either accepted) |

**Interface:** Arduino Nano Every USB-to-UART (appears as a virtual COM port).

Connect with any serial terminal program (e.g., Arduino Serial Monitor, PuTTY, minicom, screen). Send a blank line (press Enter on an empty input) to print the help text.

---

## Command Summary

| Command | Syntax | Description |
|---|---|---|
| `a` | `a <channel>` | Activate single channel (bias + sense) |
| `b` | `b <channel> <state>` | Set bias relay state |
| `s` | `s <channel> <state>` | Set sense relay state |
| `w` | `w` | Write current state to relays |
| `z` | `z` | Zero all states and write |
| `d` | `d` | Dump current state (hex) |
| `t` | `t` | Read die temperature (Kelvin) |
| `Y` | `Y` | Activate bypass line |
| `y` | `y` | Deactivate bypass line |
| *(empty)* | *(blank line)* | Print help text |

> **Case sensitivity:** Most commands are case-insensitive (processed with `strcasecmp`). The exceptions are `y`/`Y` (bypass control), which are strictly case-sensitive.

---

## Command Descriptions

---

### `a` — Activate Channel

**Syntax:** `a <channel>`

**Arguments:**
- `<channel>` — integer, 1 to 96.

**Behavior:**
1. Zeros all relay states (equivalent to `z`).
2. Enables the bias relay for `<channel>`.
3. Enables the sense relay for the board containing `<channel>`.
4. Writes the new state to the shift registers.

**Use case:** The standard command for I-V curve acquisition. Activates exactly one channel and deactivates all others.

**Example:**
```
a 42
```
Activates channel 42 (Board 1, channel 18 on that board), deactivating all other channels.

**Response:**
```
Command: <a 42>
Activating
Command complete
```

---

### `b` — Set Bias Relay

**Syntax:** `b <channel> <state>`

**Arguments:**
- `<channel>` — integer, 1 to 96.
- `<state>` — integer, 1 (activate) or 0 (deactivate).

**Behavior:**
- Sets or clears the bias relay bit for `<channel>` in `outState[]`.
- Immediately calls `writeState()` to apply the change to hardware.
- Does **not** affect the sense relay or any other channel.

**Use case:** Fine-grained bias relay control for calibration, testing, or multi-channel bias scenarios.

**Example:**
```
b 5 1
```
Energizes the bias relay for channel 5.

```
b 5 0
```
De-energizes the bias relay for channel 5.

---

### `s` — Set Sense Relay

**Syntax:** `s <channel> <state>`

**Arguments:**
- `<channel>` — integer, 1 to 96.
- `<state>` — integer, 1 (activate) or 0 (deactivate).

**Behavior:**
- In IV-Pulse Mux mode: drives `iv_on_pins[board]` HIGH (1) or LOW (0) for the board containing `<channel>`. **Does not call `writeState()`.**
- In legacy IV Mux mode: sets/clears bit 15 in `outState[board]`, then calls `writeState()`.

> **Important:** After calling `s`, you must follow with a `w` command to apply any pending shift register state changes (bias relay state is not affected by `s` alone in IV-Pulse Mux mode, since the sense relay is a direct GPIO, not a shift register bit).

**Use case:** Enable or disable the sense path independently from the bias path (e.g., to verify relay isolation).

**Example:**
```
s 10 1
```
Enables the sense relay for the board containing channel 10 (Board 0).

---

### `w` — Write State

**Syntax:** `w`

**Behavior:**
- Serializes the current `outState[]` array to the MIC5891 shift registers.
- Pulses RCLK to latch the output register (activating relay coils).
- Does not change `outState[]`.

**Use case:** Apply a previously configured relay state after using `b` and/or `s` commands without automatic write, or after manual `outState[]` manipulation (if extended in firmware).

---

### `z` — Zero State

**Syntax:** `z`

**Behavior:**
1. Sets all elements of `outState[]` to 0.
2. Drives all `iv_on_pins[]` LOW (deactivates all sense relays).
3. Calls `writeState()` to immediately de-energize all relay coils.

**Use case:** Safe reset to ensure all channels are disconnected before switching to a new configuration.

---

### `d` — Dump State

**Syntax:** `d`

**Behavior:**
- Prints the current value of `outState[0]` through `outState[3]` as hexadecimal 32-bit words, one per line.
- Does not affect hardware state.

**Output format:**
```
1
0
400000
0
```
(Example: Board 0 has bit 0 set = channel 1 bias relay active; Board 2 has bit 22 set = channel 23 on Board 2 bias relay active.)

**Use case:** Verify the expected relay state before or after a sequence of commands.

---

### `t` — Temperature Read

**Syntax:** `t`

**Behavior:**
- Enters a loop, reading the ATmega4809 internal temperature sensor once per second.
- Prints the die temperature in **Kelvin** on each iteration.
- Loop continues until any character is received on the serial port.

**Output format:**
```
298.7
298.8
299.0
...
```

**Use case:** Monitor MCU temperature inside a vacuum enclosure, primarily for environmental awareness rather than precision measurement.

---

### `Y` / `y` — Bypass Control

**Syntax:** `Y` (activate) or `y` (deactivate)

> These commands are **case-sensitive**.

**Behavior:**
- `Y` (uppercase): drives Arduino pin 12 (`BYPASS`) HIGH.
- `y` (lowercase): drives Arduino pin 12 (`BYPASS`) LOW.

**Use case:** Enable or disable the bypass signal line, which routes around the relay matrix for calibration.

> **Note:** Pin 12 is a temporary assignment (noted in firmware comments). This should be corrected in a future hardware revision.

---

### *(empty)* — Help

**Syntax:** *(blank line — press Enter with no input)*

**Behavior:**
- Prints the on-device command help text.

**Example output (IV-Pulse Mux mode):**
```
a <channel>           : activate <channel>, clearing everything else and setting bias and sense
s <channel> <state>   : set sense relay of <channel> to <state>
t                     : print temperature (Kelvin) once per second until another character is received
b <channel> <state>   : set bias relay of <channel> to <state>
d                     : dump state
w                     : write state to relays
y                     : activate BYPASS if uppercase, deactivate if lowercase
z                     : zero state (and write to relays)
```

---

## Channel Numbering

Channels are numbered **1 to 96**. The mapping to physical boards is:

| Global Channel | Board Index | Channel on Board |
|---|---|---|
| 1–24 | Board 0 | 1–24 |
| 25–48 | Board 1 | 1–24 |
| 49–72 | Board 2 | 1–24 |
| 73–96 | Board 3 | 1–24 |

Internally, the firmware computes:
```cpp
board       = (channel - 1) / channelsPerBoard;   // 0–3
chanOnBoard = (channel - 1) % channelsPerBoard;   // 0–23
```

---

## Error Handling

- If a command handler returns a non-zero status (error), the firmware prints `"Error in command"`.
- Known error conditions: channel out of range (< 1 or > 96).
- Unrecognized commands print the help text and set error status.
- **Ctrl+C** (`0x03`) aborts the sequence (`q`) loop in legacy IV-Mux mode.

---

## Example Session

```
(press Enter for help)

a <channel>           : activate <channel>, ...
...

a 1
Command: <a 1>
Activating
Command complete

d
Command: <d>
Dump
1
0
0
0
Command complete

z
Command: <z>
Zero
Command complete

t
Command: <t>
298.6
298.7
(press any key to stop)
Command complete
```

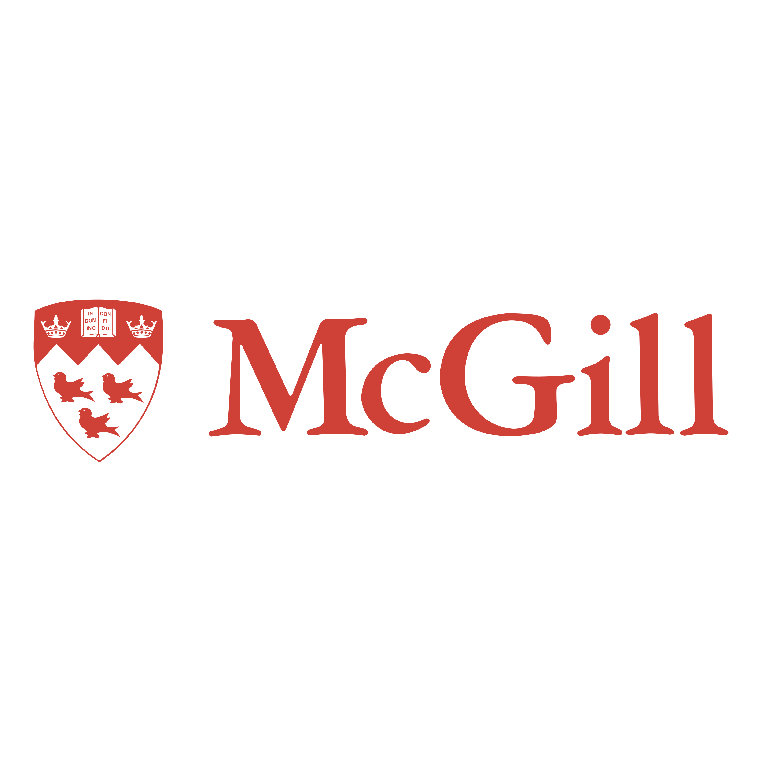
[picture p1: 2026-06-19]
reference/ETS-96-channel-IV-pulse-mux/mcgill-university-2.png

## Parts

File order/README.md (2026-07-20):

# Purchase handover — ETS breakout Board A (MCX), 96-channel system

Everything needed to place the two orders is in this folder. No project context required.
Part numbers, stock and prices were verified live **2026-07-15**; **design state 2026-07-17**
(Board A rebalanced to a ~12/13 jack split, **through-hole** MCX jack, board DRC-clean 0/0,
fab zip regenerated). Questions →
see [`../docs/BOM.md`](../docs/BOM.md) §Purchase order.

**What this buys:** 5 PCBs (4 needed + 1 spare), connectors for 4 boards + 20 % spares, and
4× SMA-to-TRB triax adapters for the IV outputs.
**Expected total ≈ $950** ($831 DigiKey + ~$90 PCB + ~$28 shipping).

| File | Use |
|---|-----|
| `board-A-mcx-jlcpcb.zip` | Gerbers + drill — upload to the JLCPCB quote wizard (both order paths) |
| `digikey-bom-connectors.csv` | **Path A (default, hand-solder):** upload to DigiKey myLists (or quick-add below) |
| `board-A-mcx-jlc-bom.csv` | **Path B (optional, JLC assembly):** the JLCPCB BOM (LCSC part numbers) |
| `board-A-mcx-jlc-cpl.csv` | **Path B:** the JLCPCB pick-and-place (CPL) |

**Two ways to build this — pick one:**
- **Path A — bare PCB fab + hand-solder (default).** JLCPCB fabricates the boards
  (`board-A-mcx-jlcpcb.zip`); the connectors come from DigiKey (`digikey-bom-connectors.csv`)
  and are hand/selective-soldered. Exact Samtec parts, footprint verified. This is Orders 1 + 2
  below.
- **Path B — JLCPCB assembled (optional).** Same gerber upload, then turn ON "PCB Assembly" and
  upload **`board-A-mcx-jlc-bom.csv`** (BOM) + **`board-A-mcx-jlc-cpl.csv`** (CPL). JLC sources
  from LCSC (QSE `C3652741`, MCX `C5137197`) and places all 26 connectors — a mixed job: SMD QSE
  on the bottom, 25 THT MCX on the top (needs JLC's through-hole assembly add-on). **Gate before
  ordering:** the MCX LCSC part (`C5137197`, BAT Wireless BWMCX-KE) is a *generic* 50 Ω THT MCX —
  confirm its land pattern (centre signal + 4 grounds on 5.08 mm, drills 1.10/1.40) and pin-1
  rotation against its drawing; if it deviates, adjust the footprint or fall back to Path A.
  (The DigiKey/Samtec files are the DigiKey-sourced hand-solder BOM — do **not** upload them to
  the JLC assembly step, or JLC reads it as DigiKey sourcing.)

---

## Order 1 — PCBs at JLCPCB (~$90 + ~$28 DHL)

> **This order is bare-PCB fab + hand-solder** (default): JLCPCB fabricates the boards, the
> connectors come from DigiKey (Order 2) and are hand/selective-soldered. An **assembled
> JLCPCB build is possible instead** — mixed SMT(QSE)+THT(MCX) using LCSC QSE `C3652741` +
> MCX `C5137197` (BAT Wireless `BWMCX-KE` generic 50 Ω THT jack; alt `C49118404`), both
> *Extended* parts, MCX needs JLC's through-hole assembly add-on. Before choosing assembly,
> confirm the `BWMCX-KE` land pattern matches our footprint (centre signal + 4 grounds,
> 5.08 mm, drills 1.10/1.40) — it's a generic equivalent, not dimensionally verified.

Go to [jlcpcb.com](https://jlcpcb.com) → **Instant Quote** → upload `board-A-mcx-jlcpcb.zip`
(**regenerated 2026-07-17** for the rebalanced layout — re-upload this current zip, not
any earlier copy). The wizard auto-detects 4 layers and **75.0 × 125.2 mm** (the balanced
~12/13 jack split shrank the board ~32 mm from the earlier revision). Set the fields:

| Wizard field | Set to |
|---|---|
| Base Material | FR-4 |
| Layers | 4 (auto-detected) |
| PCB Qty | **5** |
| Delivery Format | Single PCB |
| PCB Thickness | 1.6 mm |
| **Specify Stackup** | **Yes → JLC04161H-7628** |
| **Impedance Control** | **Yes — ±10 % (±5 Ω for ≤50 Ω)** |
| Surface Finish | **ENIG** (flat pads for the fine 0.8 mm-pitch QSE-040 SMD socket — worth the ~$18 over HASL) |
| Outer Copper Weight | 1 oz |
| PCB Color | any (green is cheapest/fastest) |
| Via Covering | default (tented) |
| Confirm Production File | Yes (recommended, ~$1) |

Paste into the **PCB Remark** field:

> 50 ohm single-ended microstrip, 0.325 mm nominal trace on outer layers (F.Cu/B.Cu)
> referenced to the adjacent inner GND plane (0.2104 mm 7628 prepreg, Dk 4.4). Adjust
> trace width to your etched stackup to hit 50 ohm (JLC04161H-7628 target is ~0.325 mm).

Indicative quote for the 75.0 × 125.2 mm board: **~$85–95 ENIG qty 5** (engineering + board +
impedance-control + file confirm + ENIG), 3–4 day build, DHL ~$28 — **re-quote in the wizard**,
the board shrank from the earlier revision. Well under JLC's 650 cm² large-board surcharge
at ~94 cm². HASL is cheaper if cost matters more than pad flatness.

## Order 2 — Connectors at DigiKey ($831.19)

Upload `digikey-bom-connectors.csv` at DigiKey → **myLists → Upload a File**, review, add to
cart. Or paste into Quick Add (`PN, qty`):

```
SAM8944-ND, 120
SAM8124-ND, 5
1097-1372-ND, 4
```

| PN | Part | Qty | Unit | Ext | Stock 2026-07-15 |
|----|---|----:|-----:|----:|---|
| SAM8944-ND | Samtec MCX-J-P-H-ST-TH1 — MCX jack, straight, **through-hole**, 50 Ω, 6 GHz | 120 | $4.21 (@100 break) | $505.20 | 11,568 |
| SAM8124-ND | Samtec QSE-040-01-L-D-A — detector-side socket | 5 | $7.27 | $36.35 | 2,021 |
| 1097-1372-ND | Cinch 3-0347-9 — coax adapter, SMA to TRB (triax) — **for IV out**, 1 per board | 4 | $72.41 | $289.64 | 147 |

> **The MCX jacks are THROUGH-HOLE** (SAM8944-ND / `MCX-J-P-H-ST-TH1`). They are
> hand- or selective-soldered, **not** reflowed. The QSE-040 socket is SMD, so Board A is a
> mixed assembly: reflow the QSE, then hand/selective-solder the 25 THT jacks per board.

**Substitution rules (important):**

- **MCX — the through-hole part is the intended one.** `MCX-J-P-H-ST-TH1` (SAM8944-ND) mates
  the plated-through signal pin the layout relies on (zero face-change vias). A valid
  mechanical **alternative** is the right-angle THT `MCX-J-P-H-RA-TH1` (SAM10607-ND) — cable
  exits sideways off the board edge, but it needs a re-layout, so only sub with intent. Never
  cross to the **75 Ω** `MCX7-J-P-H-ST-TH1` (SAM8945-ND) or the smaller `MMCX-J-P-H-ST-TH1`
  (SAM10617-ND) — wrong impedance / wrong footprint. The old SMD jack `MCX-J-P-H-ST-SM1`
  (SAM10608-ND) is **no longer this board's part** — do not order it.
- QSE: **plain suffix only.** Never `-RT1` (retention hardware — needs board holes this
  layout doesn't have). `-K` / `-TR` are pick-and-place packaging variants — unnecessary but
  harmless. If DigiKey is out: Mouser `200-QSE04001LDA` (was $5.59, 2,589 stock).

## Checklist before submitting

- [ ] JLCPCB: **bare-PCB fab** (default; assembly optional — see the intro note + LCSC PNs), current (2026-07-17) zip, qty **5**, stackup **JLC04161H-7628**, impedance control ON, ENIG, remark pasted
- [ ] DigiKey: SAM8944-ND (THT MCX) ×120 + SAM8124-ND ×5 + 1097-1372-ND ×4, no substitutions outside the rules above
- [ ] Both orders ship to the lab as usual

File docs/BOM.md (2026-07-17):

# BOM & CAD asset collection — ETS per-channel breakout boards

Consolidated bill of materials across all four board variants, plus the collected CAD
assets (datasheet, footprint, schematic symbol, 3D model) for every part. Machine-readable
master BOM: [`BOM.csv`](BOM.csv). Per-board fab BOMs live in each
`boards/board-*/fab/board-*-bom.csv`.

All four boards share the **same QSE-040 socket and mechanical**; they differ only in the
coax jack (one jack type per board). Each board = **1× QSE-040 + 25× coax jack + 4× M3 hole**.

**Designators:** the detector socket is **J5** (upstream mapping); the 25 coax jacks are
**J6…J30** (K0→J6 … K23→J29, IV→J30). Each channel identity (K0…K23, IV) is a silkscreen
label next to its jack; mounting-hole designators (MH1…) are hidden on silk.

## Master BOM

| Item | Manufacturer | MPN | Digi-Key | LCSC | Qty/board | Board(s) | Notes |
|---|---|-----|---|---|:---:|:---:|---|
| J5 socket | Samtec | QSE-040-01-L-D-A | SAM8124-ND | C3652741 | 1 | A B C D | detector-side socket; mounts on the back face. Plain (tray) suffix — do **not** sub `-RT1` (needs retention holes we don't have). LCSC `C3652741` = the exact plain -A part (JLC assembly-capable) |
| MCX jack | Samtec | MCX-J-P-H-ST-TH1 | SAM8944-ND | C5137197 | 25 | A | straight (vertical) **through-hole**, 50 Ω, 6 GHz — **confirmed orderable** (Active, verified 2026-07-15). THT signal pin plated through all layers ⇒ B.Cu channel escape lands on it with no face-change via (zero signal vias). LCSC `C5137197` (BAT Wireless `BWMCX-KE`) is a generic 50 Ω THT MCX for optional JLC assembly — **confirm its land pattern** before an assembled order; alt `C49118404` |
| SMA jack | Amphenol RF | 901-143-6RFX | ARFX1232-ND | — | 25 | B | right-angle through-hole, 50 Ω |
| U.FL jack | Hirose | U.FL-R-SMT-1(10) | — | — | 25 | C | SMT, 50 Ω — **≤60 V** working voltage (low-bias channels only) |
| SMP jack | Amphenol RF | SMP-MSLD-PCS-20 | — | — | 25 | D | vertical SMT, 50 Ω, 4.08 mm max height |
| Mounting hole | — | — | — | — | 4 | A B C D | M3 non-plated (mechanical) |

A full 96-channel system uses 4 boards of one chosen variant → **4× QSE-040 + 100× the
chosen jack** per system.

## Purchase order — final build (Board A / MCX, full 96-channel system)

**Board A is the chosen final variant.** Quantities below build 4 boards + 1 spare PCB, with
**20 % connector spares** (120 jacks, 5 sockets). All part numbers, stock and prices verified
live **2026-07-15**. The ready-to-send handover package (JLCPCB upload zip + DigiKey upload
CSV + wizard walkthrough) is in [`../order/`](../order/README.md).

| # | Item | Order PN | Source | Qty | Unit | Ext | Stock (2026-07-15) |
|---|---|---|---|----:|-----:|----:|---|
| 1 | MCX jack `MCX-J-P-H-ST-TH1` (through-hole) | **SAM8944-ND** | DigiKey | 120 | $4.21 (@100) | $505.20 | ~11,568 (breaks: 1/$6.14 · 50/$5.17 · 100/$4.21) |
| 2 | QSE socket `QSE-040-01-L-D-A` | **SAM8124-ND** | DigiKey | 5 | $7.27 | $36.35 | 2,021 (Mouser `200-QSE04001LDA` cheaper at $5.59 → $27.95, 2,589 stk — aggregator-sourced, reconfirm in cart) |
| 3 | PCB `board-A-mcx-fab.zip` (75.0 × 125.2 mm, 4-layer, controlled impedance) | — | JLCPCB | 5 | — | ~$85–95 ENIG | ~94 cm² (under JLC's 650 cm² large-board surcharge); 3–4 day build, +~$28 DHL |
| 4 | SMA-to-TRB (triax) coax adapter, Cinch `3-0347-9` — **for IV out**, 1 per board | **1097-1372-ND** | DigiKey | 4 | $72.41 | $289.64 | 147 |
| 5 | M3 screws/standoffs (mounting) | — | generic | 16+ | — | — | lab stock |

**Total ≈ $950** (DigiKey subtotal $831.19 + JLCPCB ENIG ~$85–95 + ~$28 shipping).

DigiKey Quick-Add (`PN, qty`):

```
SAM8944-ND, 120
SAM8124-ND, 5
1097-1372-ND, 4
```

**PCB ordering notes (JLCPCB tunes width at file review):**

- Order **controlled impedance** with the note: *"50 Ω single-ended microstrip, 0.325 mm
  nominal on outer layers referenced to the adjacent inner GND plane — adjust width to your
  stackup."*
- JLCPCB: 4-layer → Specify Stackup **JLC04161H-7628** (0.2104 mm 7628 prepreg to the
  adjacent inner GND plane, Dk 4.4) → Impedance Control **±10 % (±5 Ω at ≤50 Ω)**. Their
  calculator's 50 Ω width on that stackup is ~0.325 mm — our trace is at nominal. Full
  derivation (JLC calculator RS_50 = 0.3244 mm + KiCad TransLine / IPC-2141 microstrip
  formula, every input stated): [`impedance.md`](impedance.md).
- **ENIG recommended** over HASL: flatter pads for the 0.8 mm-pitch QSE-040.
- **Assembly — default fab-only + hand-solder; optional JLCPCB assembly is possible.** The
  baseline is a bare-PCB fab + hand-solder of the exact Samtec parts from DigiKey (THT MCX
  jacks are hand/selective-soldered, not reflow; the SMD QSE reflows or hand-solders). An
  **assembled JLCPCB build** is available as a mixed SMT(QSE)+THT(MCX) job using LCSC parts —
  QSE = **C3652741** (exact Samtec, plain -A), MCX = **C5137197** (BAT Wireless `BWMCX-KE`, a
  generic 50 Ω THT MCX jack; second source **C49118404**). Both are JLC-library *Extended*
  parts (per-reel feeder fee) and the 25 THT MCX jacks require JLC's through-hole/wave-solder
  assembly add-on (price it in the quote). **Gate before an assembled order:** confirm the
  `BWMCX-KE` land pattern matches our footprint (centre signal + 4 grounds on 5.08 mm, drills
  1.10/1.40) — it's a generic equivalent whose drawing was not dimensionally verified; if it
  deviates, adjust the footprint or fall back to hand-soldering the Samtec part. See the
  **LCSC** column in the master BOM.
- Jack/socket caveats: MCX `-H-ST-TH1` is the through-hole part — do **not** cross with the
  75 Ω `MCX7-J-P-H-ST-TH1` (SAM8945-ND) or the smaller `MMCX-J-P-H-ST-TH1` (SAM10617-ND). The
  right-angle THT `MCX-J-P-H-RA-TH1` (SAM10607-ND) is a valid mechanical alternative but needs
  a re-layout (cable exits sideways off the edge). QSE must be the **plain** suffix — never
  `-RT1` (retention hardware needs board holes this layout doesn't have).

## CAD asset matrix

Datasheets in [`datasheets/`](datasheets/); footprints in
[`../lib/ets-breakout.pretty/`](../lib/ets-breakout.pretty/); schematic symbols in the
single library [`../lib/ets-breakout.kicad_sym`](../lib/ets-breakout.kicad_sym); 3D STEP
models in [`../models/`](../models/).

| Part | Datasheet | Footprint | Symbol | 3D CAD |
|---|:---:|:---:|:---:|:---:|
| QSE-040-01-L-D-A | ✅ `Samtec_QSE.pdf` | ✅ | ✅ | ✅ `QSE-040-01-L-D-A.stp` |
| MCX-J-P-H-ST-TH1 (Board A, THT) | ✅ `mcx-j-p-x-st-th1-mkt.pdf` | ✅ `Samtec_MCX-J-P-H-ST-TH1` | ✅ | ⛔ gap — no vertical THT model yet (the SMD `MCX-J-P-X-ST-SM1.step` no longer matches the through-hole part) |
| 901-143-6RFX (SMA) | ✅ `Amphenol_901-143-6RFX.pdf` | ✅ | ✅ | ⛔ vendor-gated (Amphenol/SnapMagic login) |
| U.FL-R-SMT-1(10) | ✅ `Hirose_U.FL-R-SMT-1.pdf` | ✅ | ✅ | ✅ `U.FL_Hirose_U.FL-R-SMT-1_Vertical.step` |
| SMP-MSLD-PCS-20 | ✅ `Amphenol_SMP-MSLD-PCS.pdf` | ✅ | ✅ | ✅ `SMP-MSLD-PCS-20.stp` |

**3D gaps (two):**
- **Board A MCX THT** (`MCX-J-P-H-ST-TH1`) — no vertical through-hole STEP yet. The bundled
  `MCX-J-P-X-ST-SM1.step` is the old SMD variant and no longer matches Board A's part. Drop a
  vertical THT STEP into `models/` and add a `(model …)` line to `Samtec_MCX-J-P-H-ST-TH1` to
  fill it. Datasheet + footprint + symbol are present.
- **SMA 3D STEP** (Amphenol 901-143-6RFX) — behind a vendor login (Amphenol RF / SnapMagic /
  Ultra Librarian), so it isn't bundled. Everything else (datasheet + footprint + symbol) is
  present. Drop a STEP into `models/` as `SMA_Amphenol_901-143-6RFX.stp` and add a `(model …)`
  line to the SMA footprint to fill it.

## Notes

- **Schematic symbols are reference-only.** This project generates boards directly from
  [`../pinout.py`](../pinout.py) (no schematic/netlist). The QSE symbol's pin *numbers*
  (1…80) do not map 1:1 to the footprint's pad *names* (01…80) — fine for a reference
  symbol, but don't drive a layout from these without checking the pin map.
- **MCX MPN confirmed** (2026-07-15): Board A is deliberately **through-hole** —
  `MCX-J-P-H-ST-TH1` is the exact orderable straight (vertical) THT jack (`-H` = heavy gold,
  50 Ω, 6 GHz). Verified against the Samtec `mcx-j-p-x-st-th1-mkt.pdf` drawing and live DigiKey
  listing (SAM8944-ND). The THT signal pin is plated through all layers, so the QSE's B.Cu
  channel escape lands on it with **no face-change via** (zero signal vias board-wide). Do
  *not* cross with the 75 Ω `MCX7-J-P-H-ST-TH1` (SAM8945-ND) or the smaller
  `MMCX-J-P-H-ST-TH1` (SAM10617-ND); the right-angle `MCX-J-P-H-RA-TH1` (SAM10607-ND) is a
  valid mechanical alternative but needs a re-layout. (Board A previously used the SMD
  `MCX-J-P-H-ST-SM1` / SAM10608-ND — reversed 2026-07-15 in favour of the through-hole part.)
- Datasheets were collected from manufacturer/CDN sources; the SMA and SMP drawings come
  from Amphenol's public CDN, U.FL from a Hirose drawing, QSE from the Samtec QSE-series
  catalog, MCX from the Samtec through-hole drawing (`mcx-j-p-x-st-th1-mkt.pdf`,
  suddendocs.samtec.com/prints/mcx-j-p-x-st-th1-mkt.pdf).

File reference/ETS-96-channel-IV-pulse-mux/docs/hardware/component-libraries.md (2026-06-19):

# Custom Component Libraries

This document describes the custom schematic symbol and PCB footprint libraries used in the ETS 96-Channel IV-Pulse Mux project. These libraries supplement KiCad's built-in standard libraries and provide project-specific components.

---

## Library Configuration Files

### `fp-lib-table`
Defines the three project footprint libraries:

```
(fp_lib_table
  (lib (name "samtec-footprints") (uri "${KIPRJMOD}/samtec-footprints.pretty") ...)
  (lib (name "passthrough")       (uri "${KIPRJMOD}/passthrough.pretty") ...)
  (lib (name "iv-mux")            (uri "${KIPRJMOD}/iv-mux.pretty") ...)
)
```

All library paths use `${KIPRJMOD}` (KiCad project directory variable), making the project portable across workstations.

### `sym-lib-table`
Defines schematic symbol libraries:

```
(sym_lib_table
  (lib (name "samtec-QSE") (uri "${KIPRJMOD}/bias-switches-symlibs/samtec-QSE.kicad_sym") ...)
  (lib (name "iv-mux-rescue") (uri "C:/Users/eamon/.../iv-mux-rescue.kicad_sym") ...)
)
```

> ⚠️ **Important:** The `iv-mux-rescue` library references an **absolute path on the original designer's Windows machine**. On any other workstation, KiCad will not find this library until the path is updated. To fix:
> 1. In KiCad, go to **Preferences → Manage Symbol Libraries → Project Libraries**.
> 2. Update the path for `iv-mux-rescue` to point to `${KIPRJMOD}/iv-mux-rescue.kicad_sym`.

---

## Footprint Libraries

### `iv-mux.pretty/` — Core Project Footprints

| Footprint File | Component | Description |
|---|---|---|
| `Relay_StandexMeder_DIP_HighProfile_SSmod.kicad_mod` | Standex-Meder reed relay | Modified DIP footprint with high-profile clearance; `SSmod` indicates surface-mount pads variant |
| `Relay_StandexMeder_HI.kicad_mod` | Standex-Meder reed relay | High-insertion DIP footprint for tall relay packages |
| `photomos.kicad_mod` | PhotoMOS relay | Generic 4-pin SOP/DIP footprint for PhotoMOS optocoupler relay |
| `TLP170J.kicad_mod` | Toshiba TLP170J | Specific footprint for TLP170J PhotoMOS relay (SOP-4) |
| `SOP-4_3.8x4.1mm_P2.54mm.kicad_mod` | Generic SOP-4 package | 3.8 × 4.1 mm body, 2.54 mm pitch — used for alternate PhotoMOS parts |
| `MCX_Vertical.kicad_mod` | MCX coaxial connector | Vertical-mount MCX receptacle |
| `NetTie-2_SMD_Pad6mil.kicad_mod` | Net tie (6 mil pad) | Zero-ohm SMD bridge for connecting net segments |
| `NetTie-2_SMD_Pad14mil.kicad_mod` | Net tie (14 mil pad) | Zero-ohm SMD bridge, wider pad variant |
| `NetTie-2_SMD_Pad20mil.kicad_mod` | Net tie (20 mil pad) | Zero-ohm SMD bridge, widest pad variant |

### `samtec-footprints.pretty/` — Samtec QSE Connector Footprints

| Footprint File | Component | Description |
|---|---|---|
| `SAMTEC_QSE-040-01-X-D-A.kicad_mod` | Samtec QSE-040-01-X-D-A | 40-pin (2×20) board-to-board socket, standard version |
| `CONN_QSE-020-01-L-D-A_SAI.kicad_mod` | Samtec QSE-020 (20-pin) | 20-pin variant with SAI alignment pin |
| `CONN_QSE-020-01-L-D-A_SAI-L.kicad_mod` | Samtec QSE-020 (long SAI) | 20-pin variant with long SAI alignment |
| `CONN_QSE-020-01-L-D-A_SAI-M.kicad_mod` | Samtec QSE-020 (mid SAI) | 20-pin variant with medium SAI alignment |
| `QSE-040-01-L-D-A.stp` | 3D model (STEP) | STEP model for the 40-pin QSE connector (3D visualization) |

### `passthrough.pretty/` — Panel and Chassis Connectors

| Footprint File | Component | Description |
|---|---|---|
| `BNC_coax_or_triax.kicad_mod` | BNC connector | Chassis/PCB-mount BNC for coaxial or triaxial connections |
| `MCX_Molex_73415-1060_Horizontal_1.6mm-PCB.kicad_mod` | Molex 73415-1060 MCX | Horizontal MCX with 1.6 mm PCB edge offset |
| `MCX_Molex_73415-1060_Horizontal_1.6mm-PCB_NOSILK.kicad_mod` | Same, no silkscreen | Same connector footprint without silkscreen markings |
| `MountingHole_2.1mm.kicad_mod` | Mounting hole | 2.1 mm diameter plated or unplated mounting hole |
| `Gripping_hole_unplated.kicad_mod` | Gripping/strain-relief hole | Unplated hole for mechanical retention (cable or board) |

---

## Schematic Symbol Libraries

### `bias-switches-symlibs/samtec-QSE.kicad_sym`

Contains custom schematic symbols for the Samtec QSE series board-to-board connectors. These symbols match the physical pinout of the QSE-040 and QSE-020 connectors used in the project.

### `iv-mux-rescue.kicad_sym`

A KiCad "rescue" library that was automatically generated to preserve symbol definitions that could not be matched to standard library components at the time of rescue. This library should be treated as read-only and its symbols should eventually be migrated to properly named custom symbols.

> See the `sym-lib-table` note above regarding the absolute path issue for this library.

---

## McGill University Logo Assets

The following files contain the McGill University logo used on PCB silkscreen layers:

| File | Format | Use |
|---|---|---|
| `mcgill-university-2.svg` | SVG vector | Source artwork |
| `mcgill-university-2.dxf` | DXF | Imported into KiCad PCB silkscreen |
| `mcgill-university-2.png` | PNG raster | Reference image |
| `mcgill-university-2a.svg` | SVG vector | Alternate/trimmed variant |
| `mcgill-university-2a.dxf` | DXF | Alternate DXF for PCB import |

---

## Adding New Components

When adding new custom components to this project:

1. **Footprint:** Create a `.kicad_mod` file in the most appropriate `.pretty` directory (`iv-mux.pretty` for board-specific parts, `passthrough.pretty` for panel/chassis connectors).
2. **Symbol:** Add a new symbol to `bias-switches-symlibs/samtec-QSE.kicad_sym` (for connectors) or create a new `.kicad_sym` file and register it in `sym-lib-table`.
3. **3D Model:** If a STEP model is available, place it in the same `.pretty` directory and reference it in the footprint's 3D model property.
4. **Documentation:** Update this file to record the new component.

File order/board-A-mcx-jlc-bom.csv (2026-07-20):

Comment | Designator | Footprint | LCSC Part #
MCX jack 50R THT (BWMCX-KE) | J6,J7,J8,J9,J10,J11,J12,J13,J14,J15,J16,J17,J18,J19,J20,J21,J22,J23,J24,J25,J26,J27,J28,J29,J30 | Samtec_MCX-J-P-H-ST-TH1 | C5137197
QSE-040-01-L-D-A socket | J5 | SAMTEC_QSE-040-01-X-D-A | C3652741

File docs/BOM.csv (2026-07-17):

Item | Manufacturer | MPN | Digi-Key | LCSC | Description | Qty per board | Boards | Footprint | Symbol | Datasheet | 3D Model
J5 socket | Samtec | QSE-040-01-L-D-A | SAM8124-ND | C3652741 | QSE-040 board-to-board socket (mates detector QTE-040) | 1 | A,B,C,D | SAMTEC_QSE-040-01-X-D-A | QSE-040-01-X-D-A | Samtec_QSE.pdf | QSE-040-01-L-D-A.stp
Coax jack (Board A) | Samtec | MCX-J-P-H-ST-TH1 | SAM8944-ND | C5137197 (BWMCX-KE equiv; confirm footprint) | MCX jack straight vertical through-hole 50 ohm 6 GHz (confirmed orderable 2026-07-15) | 25 | A | Samtec_MCX-J-P-H-ST-TH1 | MCX-J-P-X-ST-SM1 | mcx-j-p-x-st-th1-mkt.pdf | (none - gap; vertical THT model needed)
Coax jack (Board B) | Amphenol RF | 901-143-6RFX | ARFX1232-ND |  | SMA jack right-angle through-hole 50 ohm | 25 | B | SMA_Amphenol_901-143_Horizontal | SMA_Amphenol_901-143_Horizontal | Amphenol_901-143-6RFX.pdf | (none - vendor-gated)
Coax jack (Board C) | Hirose | U.FL-R-SMT-1(10) |  |  | U.FL jack SMT 50 ohm (<=60 V working voltage) | 25 | C | U.FL_Hirose_U.FL-R-SMT-1_Vertical | U.FL-R-SMT-1_10_ | Hirose_U.FL-R-SMT-1.pdf | U.FL_Hirose_U.FL-R-SMT-1_Vertical.step
Coax jack (Board D) | Amphenol RF | SMP-MSLD-PCS-20 |  |  | SMP jack vertical SMT 50 ohm (4.08 mm max height) | 25 | D | SMP_Amphenol_SMP-MSLD-PCS-20 | SMP_Amphenol_SMP-MSLD-PCS-20 | Amphenol_SMP-MSLD-PCS.pdf | SMP-MSLD-PCS-20.stp
Mounting hole |  |  |  |  | M3 mounting hole non-plated | 4 | A,B,C,D | MountingHole_3.2mm_M3

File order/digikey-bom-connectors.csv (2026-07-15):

Digi-Key Part Number | Manufacturer Part Number | Quantity | Customer Reference
SAM8944-ND | MCX-J-P-H-ST-TH1 | 120 | MCX jack (THROUGH-HOLE) - 4 boards x 25 + 20% spares
SAM8124-ND | QSE-040-01-L-D-A | 5 | QSE-040 socket J5 - 4 boards + 1 spare
1097-1372-ND | 3-0347-9 | 4 | SMA-to-TRB triax adapter - IV out (1 per board)

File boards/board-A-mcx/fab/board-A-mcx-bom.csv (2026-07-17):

Designators | Qty | Description | Manufacturer | MPN | Digi-Key | LCSC | KiCad Footprint
J10, J11, J12, J13, J14, J15, J16, J17, J18, J19, J20, J21, J22, J23, J24, J25, J26, J27, J28, J29, J30, J6, J7, J8, J9 | 25 | MCX jack, straight (vertical) through-hole, 50 ohm | Samtec | MCX-J-P-H-ST-TH1 | SAM8944-ND | C5137197 (BWMCX-KE equiv; confirm footprint) | Samtec_MCX-J-P-H-ST-TH1
MH1, MH2, MH3, MH4 | 4 | M3 mounting hole, non-plated |  |  |  |  | MountingHole_3.2mm_M3
J5 | 1 | QSE-040 board-to-board socket (mates detector QTE-040) | Samtec | QSE-040-01-L-D-A | SAM8124-ND | C3652741 | SAMTEC_QSE-040-01-X-D-A

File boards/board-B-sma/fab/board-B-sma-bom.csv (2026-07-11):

Designators | Qty | Description | Manufacturer | MPN | Digi-Key | KiCad Footprint
IV, K0, K1, K10, K11, K12, K13, K14, K15, K16, K17, K18, K19, K2, K20, K21, K22, K23, K3, K4, K5, K6, K7, K8, K9 | 25 | SMA jack, right-angle through-hole, 50 ohm | Amphenol RF | 901-143-6RFX | ARFX1232-ND | SMA_Amphenol_901-143_Horizontal
MH1, MH2, MH3, MH4 | 4 | M3 mounting hole, non-plated |  |  |  | MountingHole_3.2mm_M3
J5 | 1 | QSE-040 board-to-board socket (mates detector QTE-040) | Samtec | QSE-040-01-L-D-A | SAM8124-ND | SAMTEC_QSE-040-01-X-D-A

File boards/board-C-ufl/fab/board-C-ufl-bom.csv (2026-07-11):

Designators | Qty | Description | Manufacturer | MPN | Digi-Key | KiCad Footprint
IV, K0, K1, K10, K11, K12, K13, K14, K15, K16, K17, K18, K19, K2, K20, K21, K22, K23, K3, K4, K5, K6, K7, K8, K9 | 25 | U.FL jack, SMT [<=60 V working voltage - low-bias use only] | Hirose | U.FL-R-SMT-1(10) |  | U.FL_Hirose_U.FL-R-SMT-1_Vertical
MH1, MH2, MH3, MH4 | 4 | M3 mounting hole, non-plated |  |  |  | MountingHole_3.2mm_M3
J5 | 1 | QSE-040 board-to-board socket (mates detector QTE-040) | Samtec | QSE-040-01-L-D-A | SAM8124-ND | SAMTEC_QSE-040-01-X-D-A

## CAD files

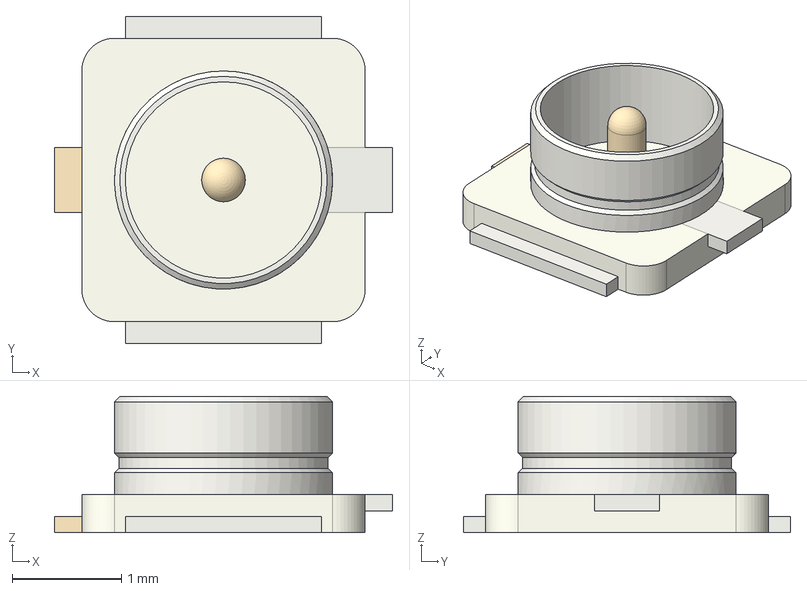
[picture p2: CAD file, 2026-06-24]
models/U.FL_Hirose_U.FL-R-SMT-1_Vertical.step
3.10 x 3.00 x 1.25 mm

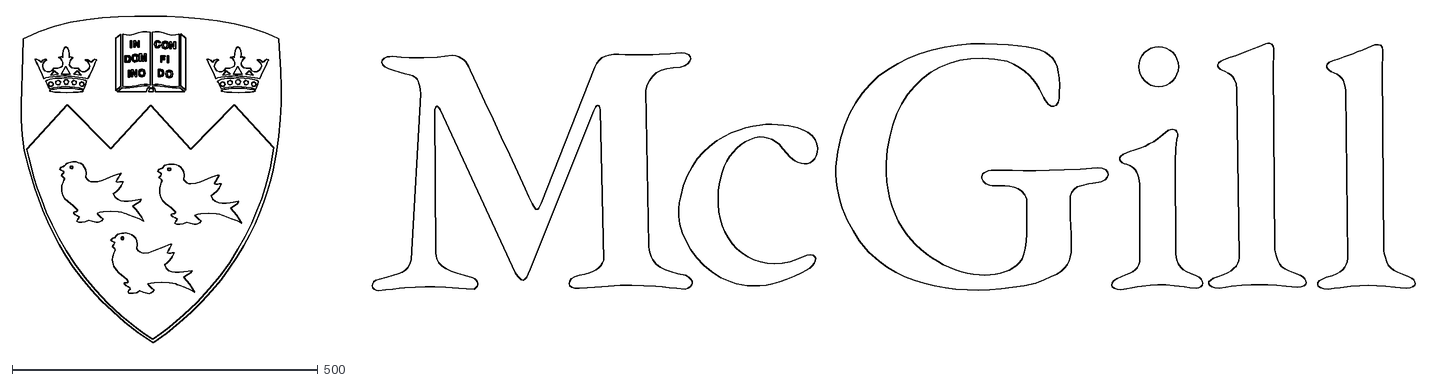
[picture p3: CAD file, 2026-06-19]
reference/ETS-96-channel-IV-pulse-mux/mcgill-university-2a.dxf
2293.2 x 534.3

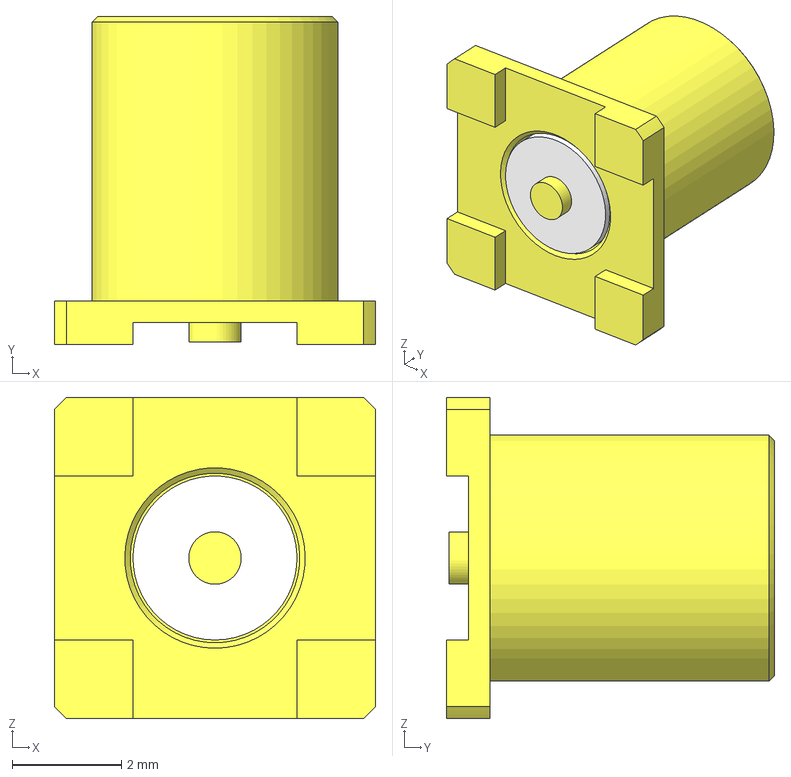
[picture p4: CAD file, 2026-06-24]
models/MCX-J-P-X-ST-SM1.step
5.88 x 6.00 x 5.88 mm
MCX-J-P-H-ST-SM1_s
MCX-J-P-H-ST-SM1_i
MCX-J-P-H-ST-SM1_p

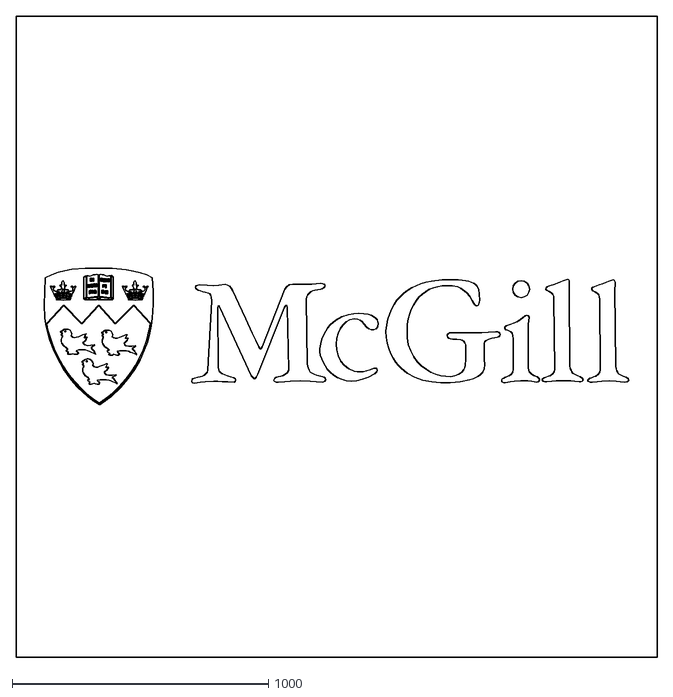
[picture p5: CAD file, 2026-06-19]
reference/ETS-96-channel-IV-pulse-mux/mcgill-university-2.dxf
2500.0 x 2500.0

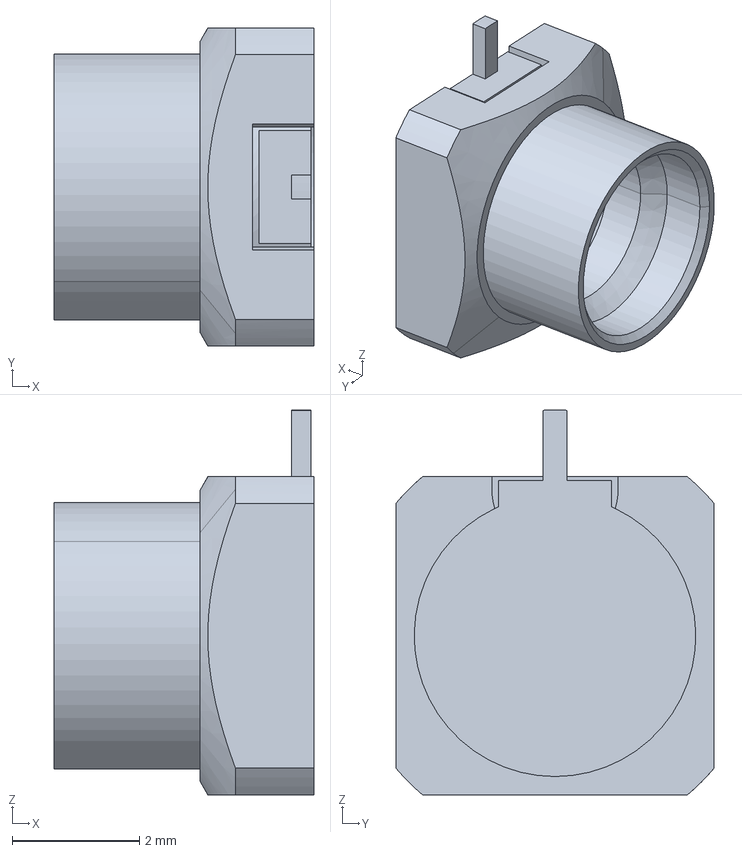
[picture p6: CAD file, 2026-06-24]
models/SMP-MSLD-PCS-20.stp
4.08 x 5.00 x 6.04 mm

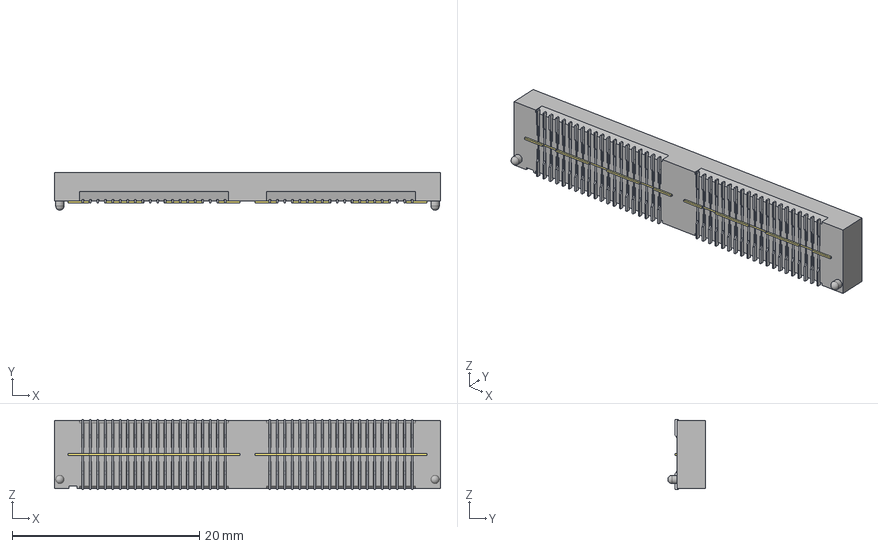
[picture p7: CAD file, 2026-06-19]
models/QSE-040-01-L-D-A.stp
41.3 x 4.01 x 7.49 mm
QSE-040-01-L-D-A-S_terminal
QSE-T-1G2-01-040 x 2
QSE-C-126-21-040-D-S-L x 2
QSE-C-126-21-040-D-S2 x 2
QSE-C-126-21-040-D-S3 x 2

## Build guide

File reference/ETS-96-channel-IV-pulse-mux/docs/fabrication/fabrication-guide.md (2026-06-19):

# Fabrication and Assembly Guide

This guide describes the process for obtaining fabricated PCBs, procuring components, and assembling the ETS 96-Channel IV-Pulse Multiplexer system.

---

## PCB Overview

The system consists of two distinct PCB designs:

| Board | KiCad Project | Qty Required |
|---|---|---|
| IV Pulse Mux board | `iv-pulse-mux.kicad_pro` | 4 |
| Motherboard | `iv-pulse-motherboard.kicad_pro` | 1 |

---

## Generating Fabrication Files

### Method 1: KiCad Job Set (Recommended)

A pre-configured KiCad job set (`fab-files.kicad_jobset`) automates generation of all required outputs:

1. Open `iv-pulse-mux.kicad_pro` in KiCad.
2. In PCB Editor (Pcbnew), go to **File → Fabrication Outputs → Run DRC** and confirm zero errors.
3. Go to **File → Fabrication Outputs → Job Set...** and open `fab-files.kicad_jobset`.
4. Click **Generate All** to produce:
   - Gerber files → `pcbfab/gerber/`
   - Drill files → `pcbfab/drill/`
   - BOM → `assembly/iv-pulse-mux-bom.csv`
   - Pick-and-place positions → `assembly/iv-pulse-mux-positions.csv`

Repeat for the motherboard project.

> **Note:** The `gerb*/` and related output directories are listed in `.gitignore` and will not be committed. Always regenerate from source before board submission.

### Method 2: Manual Gerber Export

If the job set is unavailable:

1. In PCB Editor, go to **File → Plot**.
2. Select **Gerber** format.
3. Enable all copper layers, silkscreen, solder mask, courtyard, and edge cut.
4. Set output folder to `pcbfab/gerber/`.
5. Click **Plot**, then **Generate Drill Files** and save to `pcbfab/drill/`.

### Fabrication Toolkit Options

The `fabrication-toolkit-options.json` file configures the KiCad Fabrication Toolkit plugin:

| Option | Value |
|---|---|
| All active layers exported | Yes |
| Auto-translate (origin correction) | Yes |
| Auto-fill zones before export | Yes |
| Exclude DNP components | Yes |

---

## PCB Specifications

These are the minimum specifications to request from the board fabricator. Verify against the actual KiCad DRC settings before ordering.

| Parameter | Value |
|---|---|
| Board material | FR4 (or better for low-leakage applications) |
| Copper weight (outer layers) | 1 oz (35 µm) |
| Minimum trace width | 0.2 mm |
| Minimum clearance | 0.15 mm (guard class) |
| Minimum via drill | 0.3 mm |
| Via diameter | 0.6 mm |
| Surface finish | ENIG (Electroless Nickel Immersion Gold) recommended for fine-pitch connectors |
| Solder mask | Both sides, green (or per lab preference) |
| Silkscreen | Both sides |
| Board thickness | 1.6 mm (standard) |

> **Note on substrate:** For measurements below ~1 nA, consider using a low-absorption substrate (e.g., Rogers 4003C or PTFE-based material) to minimize surface leakage current between the bias and sense conductors.

---

## Bill of Materials (BOM)

The BOM is automatically generated by the KiCad job set to `assembly/iv-pulse-mux-bom.csv`. The following table summarizes key component categories:

### Key Components — IV Pulse Mux Board (per board, 4 required)

| Reference | Component | Part Number / Value | Notes |
|---|---|---|---|
| U? (×3) | Shift register | MIC5891 | Serial-in, parallel-out, latched, 8-bit, power output |
| K? (×24) | Reed relay (bias) | Standex-Meder DIP high-profile | Exact part number in BOM |
| U? (×1) | PhotoMOS relay (sense) | TLP170J or equivalent SOP-4 | One per board |
| J1 | Board-to-board connector (header) | Samtec QSH-040-01-X-D-A | Mates with motherboard QSE socket |
| J2–J25 | MCX channel connectors | Molex 73415-1060 or vertical MCX | 24 per board |
| — | Decoupling capacitors | 100 nF, 0.1 µF | Per MIC5891 VCC pin |
| — | Relay coil flyback diodes | 1N4148 or equivalent | Across each relay coil |

### Key Components — Motherboard (1 required)

| Reference | Component | Part Number / Value | Notes |
|---|---|---|---|
| U1 | Arduino Nano Every | ABX00028 or equivalent | ATmega4809, 5 V, USB |
| J1–J4 | Board-to-board connector (socket) | Samtec QSE-040-01-X-D-A | One per mux board slot |
| J? | Bias input connector | BNC or terminal block | Per design |
| J? | Sense line connector | BNC or MCX | Per design |
| J? | Sync input connector | MCX or BNC | Optional |
| — | Bulk decoupling | 10 µF, 100 µF electrolytic | On 5 V and bias rails |

> The authoritative, complete BOM with exact manufacturer part numbers (MPN), distributor part numbers (VPN), and sourcing notes is in the generated `assembly/iv-pulse-mux-bom.csv` file. The BOM fields in the schematic include `MPN`, `MFN` (manufacturer name), `VPN`, `VN` (vendor name), and sourcing notes.

---

## Assembly Notes

### General

1. **Inspect PCBs** upon receipt: check for correct dimensions, no shorts on power pads, and confirm pad and via quality under magnification.
2. **Solder paste stencil** recommended for fine-pitch SMD components (PhotoMOS, MIC5891 if in SOIC package).
3. **Reflow soldering** for SMD components; hand soldering for through-hole relays and connectors.

### Relay Orientation

- Reed relays are polarized only in that the coil has a preferred orientation for the quiescent state. Ensure relay orientation matches the footprint silkscreen.
- The high-profile DIP housing requires sufficient pad-to-pad clearance. Verify component fits within courtyard.

### MCX Connectors

- Horizontal MCX connectors (`MCX_Molex_73415-1060_Horizontal_1.6mm-PCB`) must be aligned with the PCB edge. The 1.6 mm PCB offset is critical for panel-mount applications.
- Install MCX connectors before the board-to-board connector to allow access.

### Samtec QSE/QSH Connectors

- The QSE (socket on motherboard) and QSH (header on mux boards) connectors are precision alignment parts. Do not force mating; ensure boards are properly aligned before mating.
- The SAI alignment pin variants (`_SAI`, `_SAI-L`, `_SAI-M`) provide a keying pin to prevent mis-insertion.

### Mounting and Stacking

1. Install QSH connectors on all four mux boards.
2. Install QSE sockets on the motherboard.
3. Carefully mate each mux board perpendicular/parallel (per mechanical design) to the motherboard.
4. Secure with standoffs through mounting holes if provided.

---

## Inspection and Test After Assembly

### Visual Inspection

- Inspect all solder joints under a magnifier or microscope.
- Check for solder bridges on fine-pitch components (MIC5891, PhotoMOS).
- Verify relay coil flyback diodes are correctly oriented.

### Electrical Tests Before Powering Up

1. **Continuity test:** Verify 5 V and GND on the QSE connector pads are not shorted.
2. **Isolation test:** Verify no continuity between BIAS rail and SENSE rail.
3. **Resistance check on relays:** Coil resistance should match the relay datasheet (typically 500–1000 Ω for small reed relays).

### Firmware Bring-Up

1. Flash the firmware (see [Firmware Overview](../firmware/firmware-overview.md)).
2. Connect via serial terminal at 9600 baud.
3. Send `d` — should return four lines of `0` (all states zero after power-up).
4. Send `a 1` — the relay for channel 1 should close (audible click if in a quiet environment).
5. Send `d` — Board 0 state should show `1` (hex), Boards 1–3 should show `0`.
6. Send `z` — all relays should open.
7. Cycle through several channels with `a <n>` and verify relay actuation.

---

## Storage and Handling

- Store assembled boards in anti-static bags.
- Handle QSE/QSH connectors carefully; the alignment pins are fragile.
- Reed relays are sensitive to strong magnetic fields — store away from permanent magnets.
- If boards are to be installed in a vacuum system, allow adequate outgassing time in a low-pressure environment before sealing.

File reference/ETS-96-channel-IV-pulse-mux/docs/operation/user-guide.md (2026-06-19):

# User and Operation Guide

This guide describes how to set up, configure, and operate the ETS 96-Channel IV-Pulse Multiplexer system for I-V curve measurements.

---

## System Overview

The ETS 96-channel IV-Pulse Multiplexer connects a single bias voltage source and sense/measurement instrument to one of 96 detector channels under software command. The system is designed for:

- Sequential I-V curve characterization of detector arrays (SiPMs, photodiodes, etc.).
- Pulsed bias operation (one channel at a time, selected by the controller).
- Integration with automated measurement software via a serial command interface.

---

## Hardware Setup

### Required Equipment

| Item | Description |
|---|---|
| 1× Motherboard | Assembled and tested |
| 4× IV Pulse Mux boards | Assembled and tested |
| 1× Arduino Nano Every | Flashed with current firmware |
| 1× Computer | For serial control (USB) |
| 1× Bias power supply | Voltage source for detector bias |
| 1× SMU or electrometer | Source-measure unit for I-V curves |
| Coaxial cables (MCX) | For individual channel connections |
| *(Optional)* Sync source | Function generator or instrument trigger output |

---

### Physical Assembly

1. **Stack mux boards** on the motherboard by mating the QSH (header) connectors on the mux boards into the QSE (socket) connectors on the motherboard.
2. **Connect detectors** to the MCX connectors on the mux boards. Channel numbers are silk-screened on the PCB:
   - Board 0: Channels 1–24
   - Board 1: Channels 25–48
   - Board 2: Channels 49–72
   - Board 3: Channels 73–96
3. **Connect bias supply** to the bias input on the motherboard (BNC or terminal block, labeled `BIAS_IN`).
4. **Connect sense line** from the SMU or electrometer to the sense input on the motherboard.
5. **Connect Arduino** to the control PC via USB.
6. *(Optional)* Connect external trigger source to the SYNC input (MCX/BNC).

---

### Power-Up Sequence

1. Ensure all relay states are in a known off condition (firmware initializes to zero on power-up).
2. Power the Arduino via USB.
3. Apply the bias supply (start at 0 V and ramp to operating voltage gradually).
4. Verify through the serial interface that all states are zero (`d` command should return four lines of `0`).
5. Activate channels as required for measurements.

### Power-Down Sequence

1. Ramp bias supply to 0 V.
2. Send `z` command to zero all relay states.
3. Power off the bias supply.
4. Disconnect USB / power off Arduino.

---

## Serial Interface

Connect to the Arduino Nano Every using any serial terminal at **9600 baud, 8N1, no flow control**.

On most operating systems, the Arduino Nano Every appears as:
- **Windows:** `COMx` (check Device Manager)
- **Linux:** `/dev/ttyACM0` or `/dev/ttyUSB0`
- **macOS:** `/dev/cu.usbmodem...`

### Example: Linux / macOS (using `screen`)
```bash
screen /dev/ttyACM0 9600
```

### Example: Windows (using PuTTY)
Select "Serial", enter the COM port, set speed to 9600, click Open.

Press **Enter** on an empty line to display the command help.

---

## Basic Operation

### Activating a Single Channel

To connect channel N to the bias and sense lines:
```
a <N>
```

Example — activate channel 42:
```
a 42
```

This:
1. Disconnects all other channels (zeros state).
2. Closes the bias relay for channel 42.
3. Enables the sense relay for Board 1 (which contains channels 25–48).
4. Applies the change to hardware.

The detector on channel 42 is now connected to both the bias supply and the sense instrument. You can now trigger an I-V sweep from the measurement instrument.

### Deactivating All Channels

```
z
```

### Verifying State

```
d
```

Returns four hex numbers representing the 24-bit bias relay state of each board. A `1` in bit position 0 of the first word means channel 1 is active.

---

## Automated I-V Sweep (Software Integration)

For fully automated multi-channel I-V characterization, the serial interface can be driven from a host script (Python, LabVIEW, MATLAB, etc.).

### Example Python Snippet

```python
import serial
import time

ser = serial.Serial('/dev/ttyACM0', 9600, timeout=2)
time.sleep(2)  # wait for Arduino to reset after serial connection

def activate_channel(ch):
    cmd = f'a {ch}\n'
    ser.write(cmd.encode())
    response = ser.read_until(b'Command complete\n')
    return response

def zero_all():
    ser.write(b'z\n')
    ser.read_until(b'Command complete\n')

# Example: sweep channels 1 to 96
for channel in range(1, 97):
    activate_channel(channel)
    # --- trigger your SMU I-V sweep here ---
    time.sleep(0.1)  # allow relays to settle (~10 ms typical)

zero_all()
ser.close()
```

### Relay Settling Time

Allow at least **10–20 ms** after activating a channel before triggering a measurement. Reed relays have a typical operate/release time of 0.5–5 ms; allow additional time for contact bounce to settle in precision measurements.

---

## Bypass Line

The bypass signal (Arduino pin 12) can route a signal around the relay matrix:

```
Y      ← activate bypass (uppercase Y)
y      ← deactivate bypass (lowercase y)
```

The purpose and external circuit for the bypass line should be documented in the motherboard schematic. Verify its connection before use.

---

## Temperature Monitoring

The `t` command reads the ATmega4809 internal die temperature:

```
t
```

Output (Kelvin, one reading per second):
```
298.4
298.5
...
```

Press any key to stop. This is useful for monitoring the thermal environment if the system is deployed in an enclosed or vacuum space.

> **Important:** The die temperature reflects MCU self-heating plus ambient. It is not a precision measurement and should not be used as a calibrated temperature reference.

---

## Multi-Board Architecture Notes

All four mux boards operate in parallel from the same SRCLK and RCLK lines. When `a <channel>` is called:
- Only the board containing the requested channel will have a non-zero shift register state.
- The sense relay (`IV_ON`) for that board's Arduino pin is driven HIGH.
- All other boards have all relays de-energized.

This ensures that at any given time, **at most one detector channel** is connected to the bias and sense lines, preventing cross-talk or simultaneous connections.

---

## Troubleshooting

| Symptom | Likely Cause | Action |
|---|---|---|
| No serial response | Wrong COM port or baud rate | Verify port and use 9600 baud, 8N1 |
| `Error in command` | Channel out of range (< 1 or > 96) | Use valid channel numbers |
| Relay does not actuate | Shift register not initialized | Send `z` then `a <ch>` again |
| All channels on board N not working | IV_ON signal not working | Check Arduino pin A(N) and PhotoMOS relay on that board |
| Channel heard clicking but no current measured | Sense relay not closing | Verify `iv_on_pins[board]` wiring and PhotoMOS relay |
| State does not update after `s` command | `s` does not auto-write in IV-pulse-mux mode | Follow `s` with `w` |
| Temperature reads as 0 or garbage | VREF not set up correctly | This is a firmware-level issue; check ATmega4809 ADC configuration |
| Firmware upload fails | Wrong board selected | Select "Arduino Mega or Mega 2560" in Arduino IDE — the Nano Every (ATmega4809) requires this board profile in this project; see [Firmware Overview](../firmware/firmware-overview.md) |

---

## Safety Precautions

1. **High voltage:** The bias supply may operate at tens to hundreds of volts depending on the detector type. Follow standard HV safety practices. Ensure the bias supply is ramped down before connecting or disconnecting detector cables.
2. **ESD:** Reed relays and detectors (SiPMs especially) are ESD-sensitive. Handle all boards and connectors with appropriate ESD precautions (grounded wrist strap, anti-static mat).
3. **Vacuum operation:** If the system is operated in a vacuum enclosure, ensure components have been properly outgassed and that no volatile materials are present.
4. **No simultaneous bias on multiple channels:** The firmware enforces single-channel operation with the `a` command. However, the `b` command allows direct bias relay control without zeroing — take care not to inadvertently connect bias to multiple channels simultaneously if using `b` directly.

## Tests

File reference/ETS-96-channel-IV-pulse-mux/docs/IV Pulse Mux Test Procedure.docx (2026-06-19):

## 1.1 Configuration

### 1.1.1 Boards

This test contemplates a backplane and a single mux board. It can also be adapted for multiple mux boards.

### 1.1.2 Connections

Motherboard Arduino is powered and controlled from USB. (Serial port is also possible but the firmware must be reconfigured.)

Electrometer input connected to Mux board IV out, or to backplane IV out, as needed

### 1.1.3 Jumpers

#### 1.1.3.1 Motherboard

JP5: supplies +5V power to shift registers, via 12 – 5V linear regulator U2

Other jumpers uninstalled.

#### 1.1.3.2 MUX board

JP2: connects VB_POS

JP1: install if testing IV_OUT on backplane.

Other jumpers uninstalled.

## 1.2 Functional Tests

These are some quick tests to:

- determine the leakage of the board
- ensure the relay activation works
- ensure the diodes are the right way around

Board leakage in the bias circuit can be tested prior to plugging in relays. This allows isolation of relay leakage and board leakage.

### 1.2.1 Bias Relay Activation

#### 1.2.1.1 Coil Voltage

Check for +12V on pin 2 when the channel is selected.

VB should be present on pin 7 (passed by the photomos), if and only if the channel is selected.

#### 1.2.1.2 Bypass

To bypass the relay (bias circuit), jump pins 1-7.

### 1.2.2 Sense Relays

Put the sense relays in both states and check that the relays are alternately closed or open.

### 1.2.3 PIN Diodes

## 1.3 IV Mode Tests

For these tests:

- IV out line is connected to the electrometer (Triax connection TBD)
  - Both mux IV out and backplane IV out must be tested at some point
  - The mux output can be used initially, to remove any issues about the backplane connector
- To protect the electrometer, use a series resistor here or on the Vb source
- Component references are to the first channel or first channel group.

### 1.3.1 Noise Level

- Assess susceptibility to nearby movements etc which may create dynamic electric fields that induce noise. Also, 60Hz fields are a possibility, which can be partially canceled by the correct electrometer integration timing setting (power-line cycles)
- Assess electrometer reading noise level and reduce it to the level needed (~1pA?) using electrostatic shielding
- This can be with no voltages applied to the circuit
- This ensures the current reading noise level is negligible before we consider any leakage currents

### 1.3.2 Sense Line Leakage from +12V

- Nothing is plugged in to the SiPM connector
- All bias relays off
- Sense relay off (IV_ON low)
- Let electrometer reading settle
- Turn +12V on and look at any change in electrometer reading
- Sense relay on (IV_ON high)
- Turn +12V on and look at any change in electrometer reading

### 1.3.3 Bias Relay Leakage from VB, no SiPM connections biased, no connector present

Will measure any leakage from VB to sense, independent of the HD connector.

- Nothing is plugged in to the SiPM connector
- All bias relays off, sense relay on

Apply and remove VB and check for any related change in electrometer current

#### 1.3.3.1 Result 2025-02-03

VB was 50V.

We measured this in the previous week and concluded there was no significant leakage.

We re-measured it today and saw ~6pA which goes to 100-500fA when VB is removed.

### 1.3.4 Bias Relay Leakage from +12V, no SiPM connections biased

No test is required, since +12V will only be present on a given relay connection, if it is active.

Leakage current is assumed to be negligible compared with VB connection (via the bias resistors).

### 1.3.5 Bias Relay Leakage from VB, no SiPM connections biased, all bias lines inactive but shorted

Will measure any leakage from VB to any inactive cathode bias trace.

- Jumper all of the SiPM connections (K-A) on the Tile Interface (with 2mm jumpers). This may also be done in sets of SiPM connections.
- Plug Tile Interface (directly) into SiPM connector
- Activate the sense relay connection through to the electrometer, using the command e.g. s 1 1 (sense relay, channel 1, on).

Apply and remove VB and check for any related change in electrometer current

Further diagnosis:

- If a change with connection / disconnection of Vb is seen here (but not in test 1.3.1), narrow down which channels (jumpers) are responsible for the leakage. The problem is probably found in the relay circuit.

#### 1.3.5.1 Result 2025-02-03

We did this on the first 8 channels, one at a time.

The TIB was plugged in directly, a

Readings are with moving average filter set to 100 samples. A significant amount of reading noise was seen.

We need to track down whether this comes from

- the TIB or adapter board being connected
- wires being connected to the adapter board
- the wires actually being shorted

Channel | Reading 1 (pA) | Reading 2 (pA)
1 | 60 | 75
2 | 24
3 | 22
4 | 27
5 | 23
6 | 21
7 | 24
8 | 220 (maybe no moving average) | 94

#### 1.3.5.2 Result 2025-02-07

With a power supply of 12V, we see a current of 200 pA. When power supply is turned off, the two big relays have 3.6 Vs across them, and we see a current of about 62pA. This is consistent as (200/62)*12=3.7V.

Having the Arduino powered puts a residual voltage on the 12V pin even then the 12V is absent.

On cutting of the relay pin, we see the leakage goes down to 0.05pA, bouncing back and forth between +/-, with bias and power supply on.

On removing the relay and activating bias channel 1, we see a less than a pA current. --So the relays are an issue.

With the series relay bypassed and the shunt relay disconnected, we see <1pA with no bias populated, and nothing plugged in to the HD connector.

Mystery

When we connect the TIB to the HD connector, we see ~50-60pA (with the 100 sample MA(((((moving aaveraverage)MAmoving average)-moving average)-moving average filter). We didn’t see this in 1.2.5.1. Getting more noise because the TIB and adapter are connected is normal since the anode connection isn’t shielded by proximity to the board. But how can plugging in the TIB result in a net positive current?

Where is the reading noise coming from? Is it leaking in from outside? Is it higher frequency? Is it from the Arduino? Unplugging the Arduino and powering down the 12V, we don’t see any dramatic reduction in reading noise.

With the relays removed and Ch 8 SiPM shorted, we don’t see any evidence of Vb-related leakage current. (Still need to test this with the relays in place.)

To be done: Leakage check on channels 1-8 after sonication of boards

Ch 8- no significant leakage excess seen when ch8 was activated/ deactivated.

### 1.3.6 Leakage through photomos

It will be interesting to sample the leakage through the photomos with Vb = 50V, by measuring the voltage present on R11

### 1.3.7 Adjacent Bias Line Leakage

- With all SiPM connections jumpered (K-A) on connected Tile Interface

This test chiefly checks for leakage from any one active cathode bias line, into any of the other cathode lines. Note that although the procedure calls for all of the other channels to be jumpered, it may be adequate to only jumper channels adjacent or close to the active channel.

For each of 24 channels:

- Zero state
- Apply VB
- Remove jumper on connector for channel under test
- Jumper adjacent channels on connector
- Activate the channel and measure

Check for any change in electrometer reading that is related to channel or VB activation

Further diagnosis:

- If significant change is found, determine whether it depends on adjacent jumpers being connected (i.e. it’s via other bias lines). If not, it may be directly on the channel itself.
- If it appears to be directly on the channel, repeat with tile interface removed, as this could be the source of the leakage.

## 1.4 Pulse Mode Tests

### 1.4.1 Noise

The only potential noise source on the board is probably the Arduino. Therefore we can assess whether it noticeably increases the noise floor. However, to turn on a pulse output path, the Arduino is needed (unless we try some hack).

Therefore, let’s do the following to start with.

Look at, capture, and compare the RF output noise level with Arduino on and off.

With Arduino on, activate some channels and compare the RF output noise level.

- Channels terminated with short or 50 ohms (at the HD connector)
- Channels left open

### 1.4.2 Attenuation and distortion

- With 50 ohm drive
  - Check attenuation versus straight through with 50 ohm termination
- With high impedance drive
- Look at attenuation and distortion
- Start with 50nS pulse, reduce to shorter pulse

### 1.4.3 Supplementary

VNA sweep (frequency)

Cable test sweep

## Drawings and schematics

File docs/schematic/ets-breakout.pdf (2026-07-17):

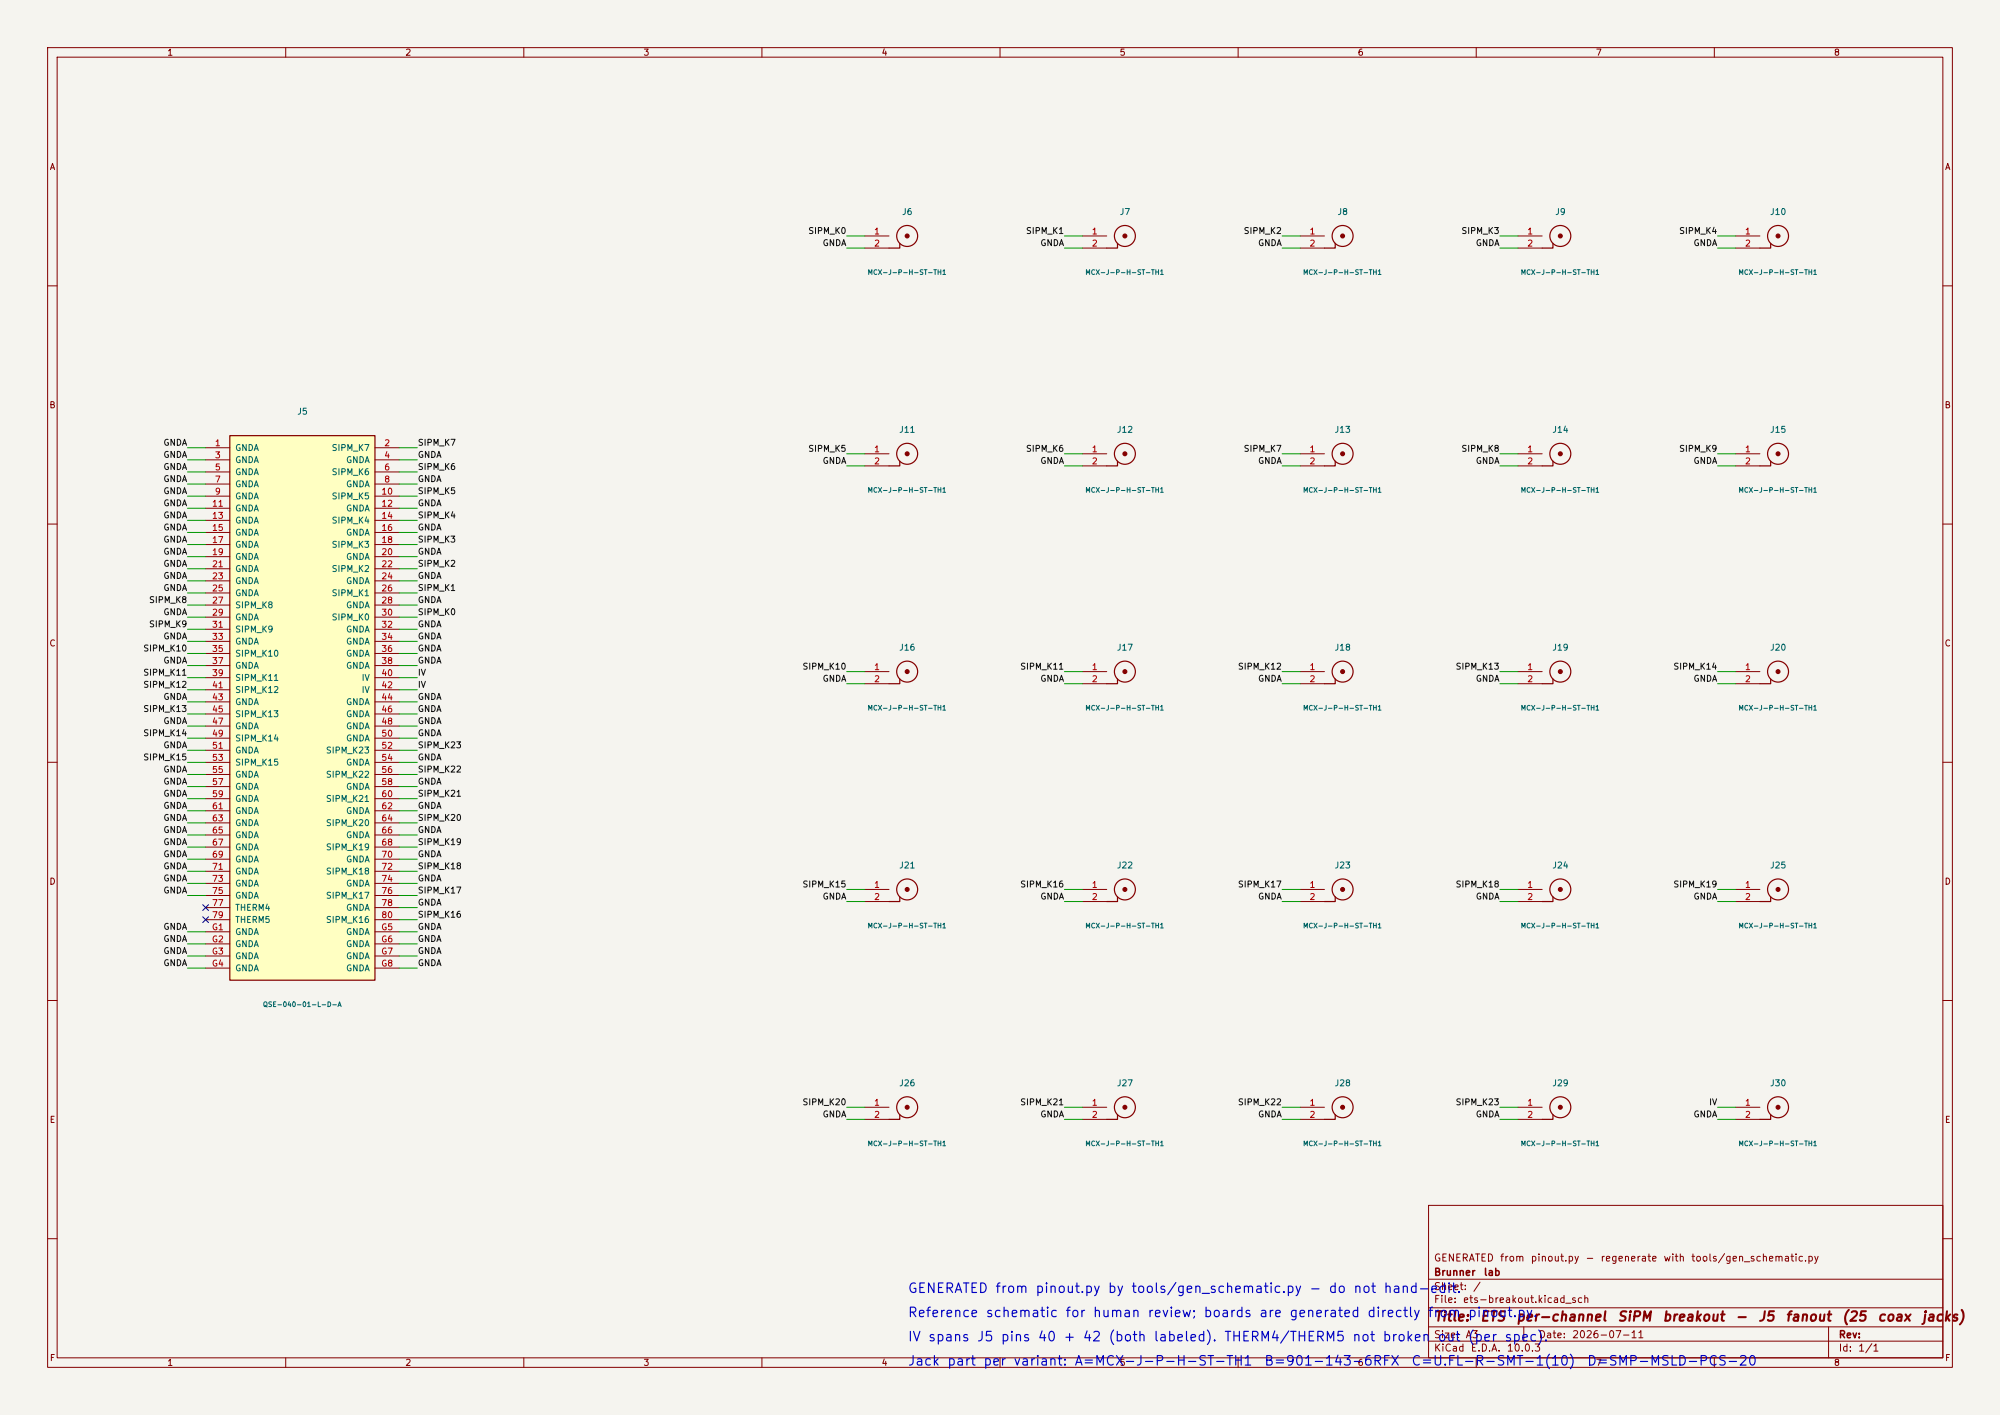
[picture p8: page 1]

GENERATED from pinout.py - regenerate with tools/gen_schematic.py
Brunner lab
Sheet: /
File: ets-breakout.kicad_sch
Title: ETS per-channel SiPM breakout - J5 fanout (25 coax jacks)

GENERATED from pinout.py by tools/gen_schematic.py - do not hand-edit.
IV spans J5 pins 40 + 42 (both labeled). THERM4/THERM5 not broken out (per spec).
Jack part per variant: A=MCX-J-P-H-ST-TH1 B=901-143-6RFX C=U.FL-R-SMT-1(10) D=SMP-MSLD-PCS-20

Size: A3 | Rev:
KiCad E.D.A. 10.0.3 | Id: 1/1 | F Date: 2026-07-11

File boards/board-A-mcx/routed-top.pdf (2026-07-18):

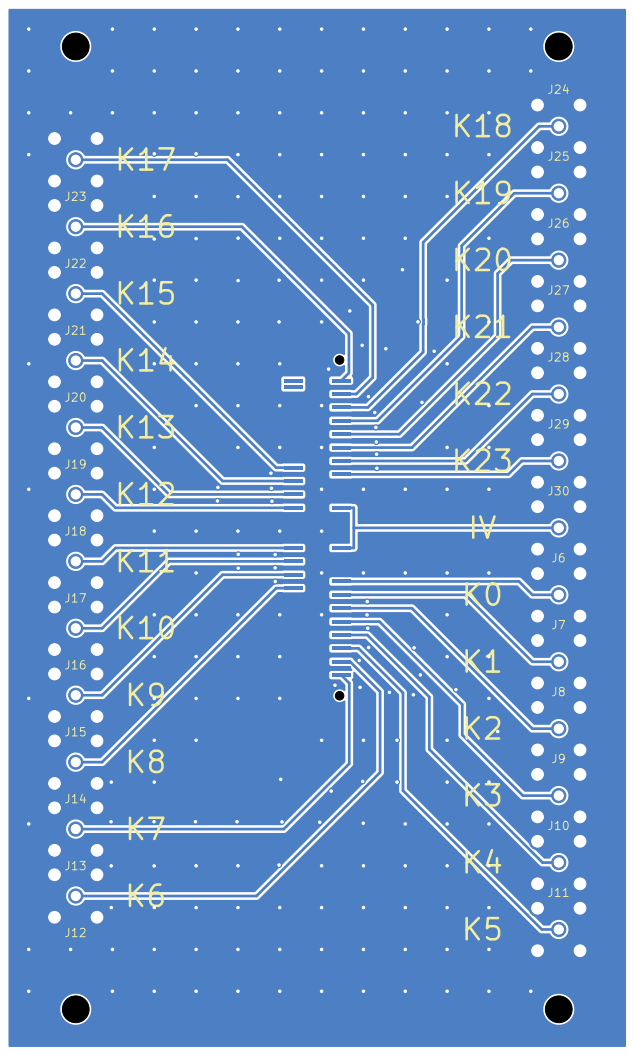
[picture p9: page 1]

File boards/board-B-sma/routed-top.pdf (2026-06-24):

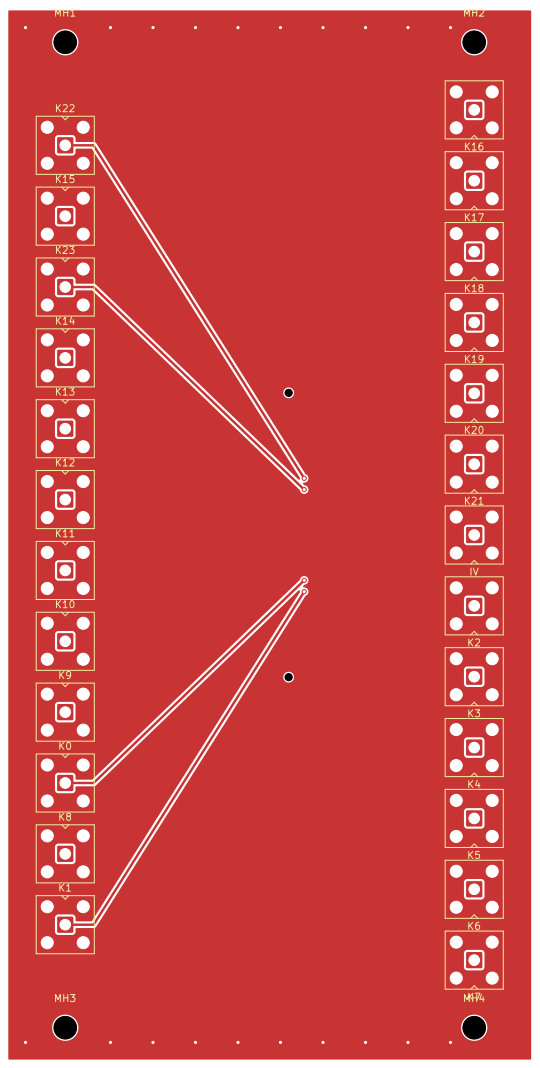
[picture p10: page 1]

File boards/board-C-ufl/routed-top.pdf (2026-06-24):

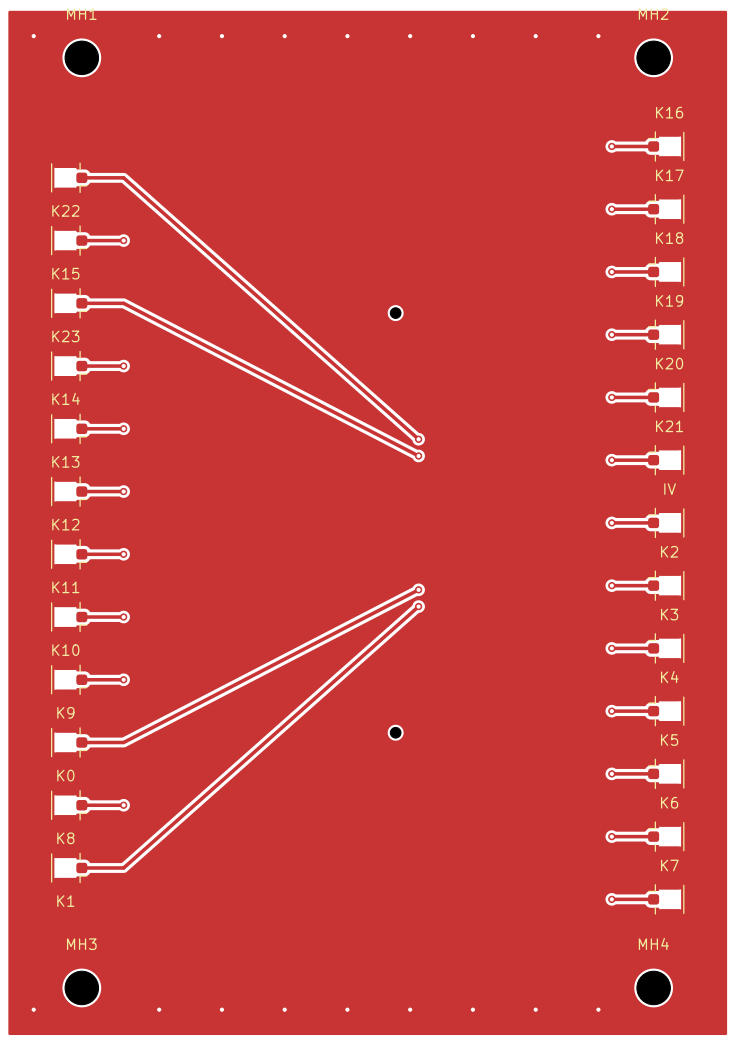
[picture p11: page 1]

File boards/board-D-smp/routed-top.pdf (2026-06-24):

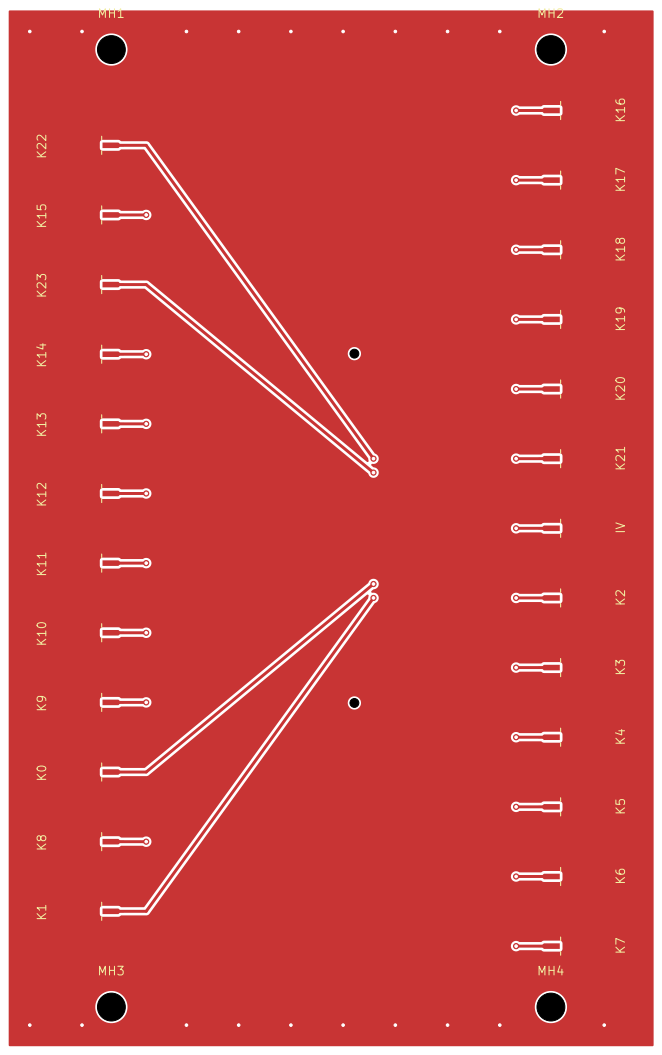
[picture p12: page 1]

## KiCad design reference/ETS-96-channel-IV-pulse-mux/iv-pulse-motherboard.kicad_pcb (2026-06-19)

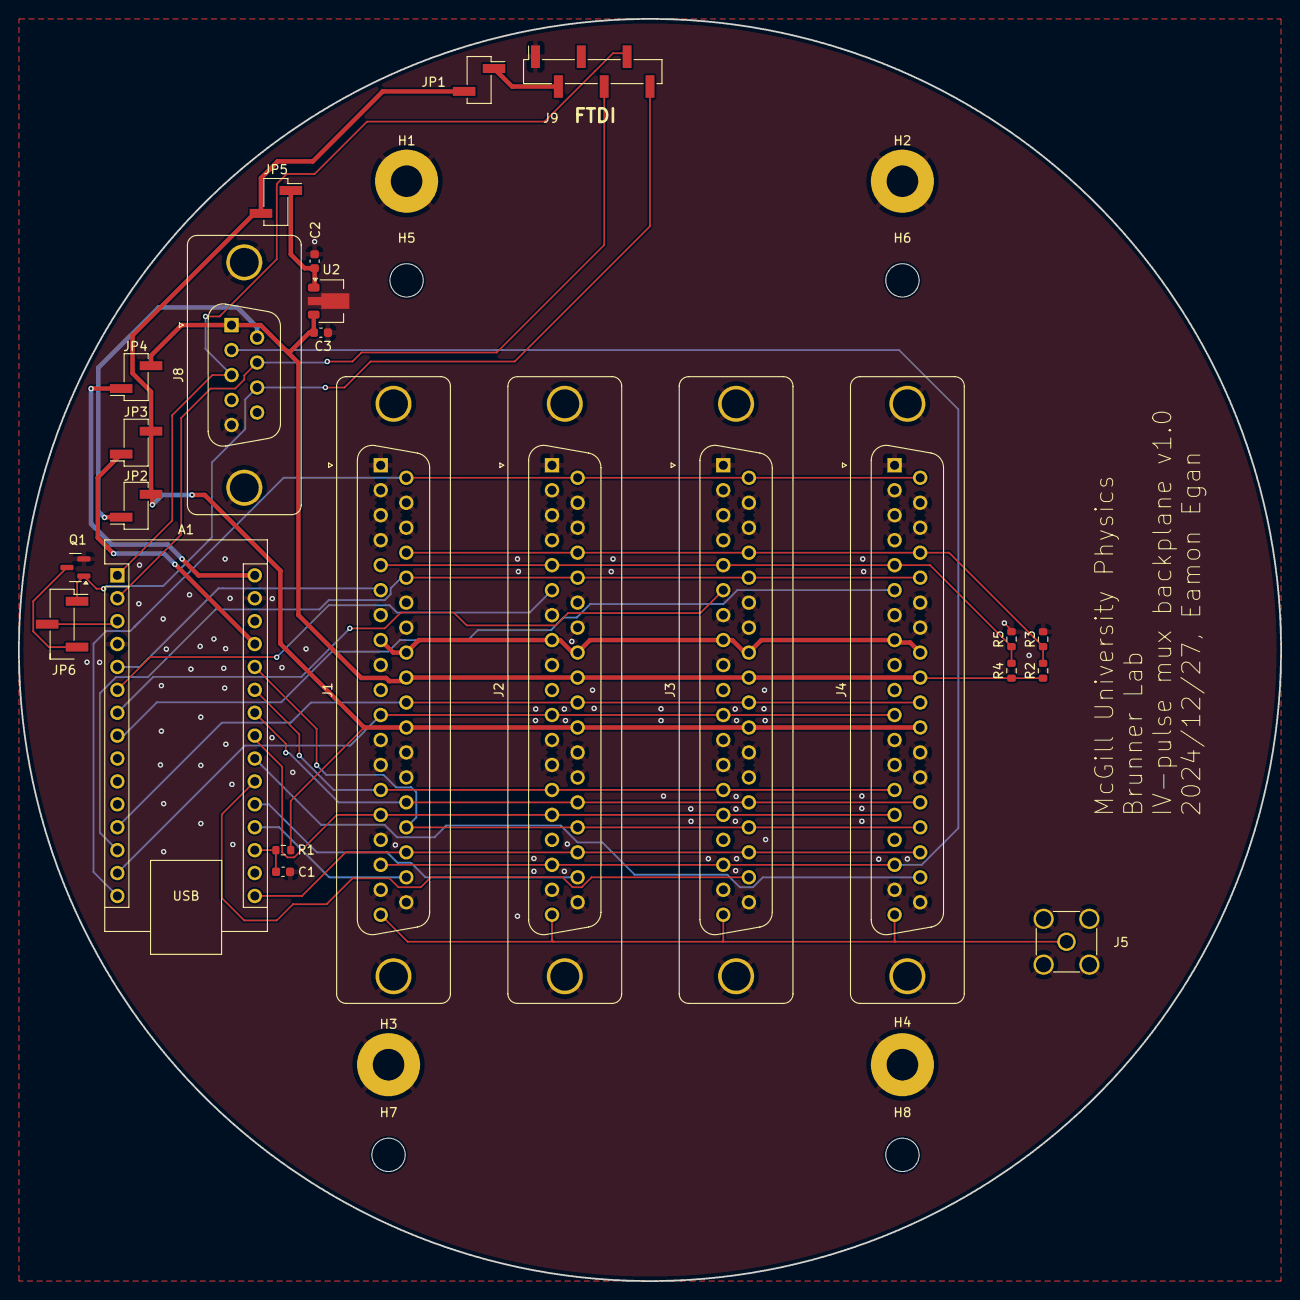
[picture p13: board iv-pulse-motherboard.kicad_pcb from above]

Board: 2 copper layers, 140.0 x 140.0 mm, 32 parts (0 on the bottom side), 36 nets.

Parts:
A1: Arduino_Nano_Every; Arduino_Nano
C1, C2, C3: C; C_0603_1608Metric
H1, H2, H3, H4: MountingHole_Pad; MountingHole_3.5mm_Pad
H5, H6, H7, H8: MountingHole; MountingHole_3.7mm
J1, J2, J3, J4: DC37_Receptacle_MountingHoles; DSUB-37_Female_Vertical_P2.77x2.84mm_MountingHoles
J5: Conn_Coaxial; SMA_Amphenol_901-144_Vertical
J8: DE9_Receptacle_MountingHoles; DSUB-9_Female_Vertical_P2.77x2.84mm_MountingHoles
J9: Conn_01x06; PinHeader_1x06_P2.54mm_Vertical_SMD_Pin1Right
JP1, JP2, JP3, JP4, JP5: Jumper_2_Open; PinHeader_1x02_P2.54mm_Vertical_SMD_Pin1Right
JP6: Jumper_3_Open; PinHeader_1x03_P2.54mm_Vertical_SMD_Pin1Right
Q1: 2N7002; SOT-23
R1, R2, R3, R4, R5: R_US; R_0603_1608Metric
U2: L78L05_SOT89; SOT-89-3

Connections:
+5V: J1.30, J2.30, J3.30, J4.30, JP1.2 (B), JP2.2 (B), JP3.2 (B), JP5.2 (B), R1.1
+12V: C3.1, J1.28, J2.28, J3.28, J4.28, J8.1, JP4.2 (B), R2.1, R4.1, U2.3 (IN)
/FTDI_RTS: J8.8, J9.6, JP6.1 (A), Q1.1 (G)
/FTDI_RXD: A1.1 (TX1), J8.3, J9.5
/FTDI_TXD: A1.2 (RX1), J8.7, J9.4
/Mux Boards/BYPASS: A1.15 (MISO/D12), J1.20, J2.20, J3.20, J4.20
/Mux Boards/IV_ON: A1.16 (SCK/D13), J1.35, J2.35, J3.35, J4.35
/Mux Boards/IV_OUT: J1.19, J2.19, J3.19, J4.19, J5.1 (In)
/Mux Boards/PIN_BIAS1: J1.23, J2.23, J3.23, J4.23, R2.2, R3.1
/Mux Boards/PIN_BIAS2: J1.5, J2.5, J3.5, J4.5, R4.2, R5.1
/Mux Boards/RCLK: A1.13 (D10), J1.24, J2.24, J3.24, J4.24
/Mux Boards/SER_IN_1: A1.5 (D2), J1.6
/Mux Boards/SER_IN_2: A1.6 (D3), J2.6
/Mux Boards/SER_IN_3: A1.7 (D4), J3.6
/Mux Boards/SER_IN_4: A1.8 (D5), J4.6
/Mux Boards/SRCLK: A1.12 (D9), J1.29, J2.29, J3.29, J4.29
/Mux Boards/VB_POS: J1.17, J2.17, J3.17, J4.17, J8.2
/Mux Boards/~OE: A1.14 (MOSI/D11), J1.11, J2.11, J3.11, J4.11
/THERM1: A1.19 (A0), J1.36
/THERM2: A1.20 (A1), J2.36
/THERM3: A1.21 (A2), J3.36
/THERM4: A1.22 (A3), J4.36
/THERMSEL0: A1.23 (SDA/A4), J1.15, J2.15, J3.15, J4.15
/THERMSEL1: A1.24 (SCL/A5), J1.33, J2.33, J3.33, J4.33
/THERMSEL2: A1.25 (A6), J1.14, J2.14, J3.14, J4.14
/THERM_ON: A1.26 (A7), J1.34, J2.34, J3.34, J4.34
GNDA: A1.4 (GND), A1.29 (GND), C1.1, C2.2, C3.2, H1.1, H2.1, H3.1, H4.1, J1.0 (PAD), J1.1, J1.2, J1.3, J1.4, J1.7, J1.9, J1.12, J1.13, J1.16, J1.18, J1.21, J1.22, J1.25, J1.26, J1.31, J1.32, J1.37, J2.0 (PAD), J2.1, J2.2, J2.3, J2.4, J2.7, J2.9, J2.12, J2.13, J2.16, J2.18, J2.21, J2.22, J2.25, J2.26, J2.31, J2.32, J2.37, J3.0 (PAD), J3.1, J3.2, J3.3, J3.4, J3.7, J3.9, J3.12, J3.13, J3.16, J3.18, J3.21, J3.22, J3.25, J3.26, J3.31, J3.32, J3.37, J4.0 (PAD), J4.1, J4.2, J4.3, J4.4, J4.7, J4.9, J4.12, J4.13, J4.16, J4.18, J4.21, J4.22, J4.25, J4.26, J4.31, J4.32, J4.37, J5.2 (Ext), J8.0 (PAD), J8.5, J9.1, Q1.2 (S), R3.2, R5.2, U2.2 (GND)
GNDD: J1.8, J1.27, J2.8, J2.27, J3.8, J3.27, J4.8, J4.27
unnamed: A1.27 (+5V), JP3.1 (A)
unnamed: A1.18 (AREF), C1.2, R1.2
unnamed: A1.30 (VIN), JP4.1 (A)
unnamed: J9.2, JP1.1 (A)
unnamed: J8.6, JP2.1 (A)
unnamed: C2.1, JP5.1 (A), U2.1 (OUT)
unnamed: JP6.3 (B), Q1.3 (D)
unnamed: A1.3 (~RESET), JP6.2 (C)

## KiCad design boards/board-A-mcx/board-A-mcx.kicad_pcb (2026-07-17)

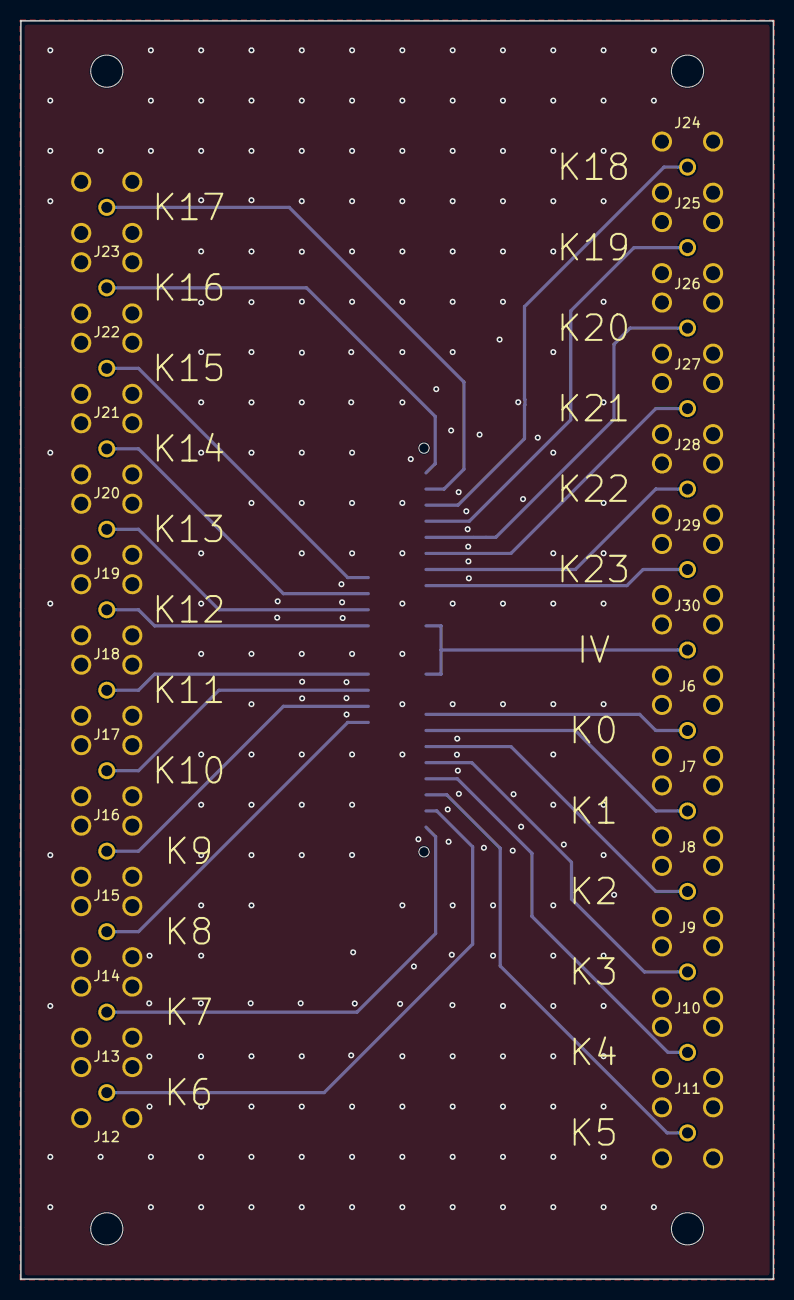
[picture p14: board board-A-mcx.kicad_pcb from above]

Board: 4 copper layers, 74.8 x 125.1 mm, 30 parts (1 on the bottom side), 26 nets.

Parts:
J5: SAMTEC_QSE-040-01-X-D-A
J6, J7, J8, J9, J10, J11, J12, J13, J14, J15, J16, J17, J18, J19, J20, J21, J22, J23, J24, J25, J26, J27, J28, J29, J30: Samtec_MCX-J-P-H-ST-TH1
MH1, MH2, MH3, MH4: MountingHole_3.2mm_M3

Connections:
GNDA: J5.01, J5.03, J5.04, J5.05, J5.07, J5.08, J5.09, J5.11, J5.12, J5.13, J5.15, J5.16, J5.17, J5.19, J5.20, J5.21, J5.23, J5.24, J5.25, J5.28, J5.29, J5.32, J5.33, J5.34, J5.36, J5.37, J5.38, J5.43, J5.44, J5.46, J5.47, J5.48, J5.50, J5.51, J5.54, J5.55, J5.57, J5.58, J5.59, J5.61, J5.62, J5.63, J5.65, J5.66, J5.67, J5.69, J5.70, J5.71, J5.73, J5.74, J5.75, J5.78, J5.G1, J5.G2, J5.G3, J5.G4, J5.G5, J5.G6, J5.G7, J5.G8, J6.2, J7.2, J8.2, J9.2, J10.2, J11.2, J12.2, J13.2, J14.2, J15.2, J16.2, J17.2, J18.2, J19.2, J20.2, J21.2, J22.2, J23.2, J24.2, J25.2, J26.2, J27.2, J28.2, J29.2, J30.2
IV: J5.40, J5.42, J30.1
SIPM_K0: J5.30, J6.1
SIPM_K1: J5.26, J7.1
SIPM_K2: J5.22, J8.1
SIPM_K3: J5.18, J9.1
SIPM_K4: J5.14, J10.1
SIPM_K5: J5.10, J11.1
SIPM_K6: J5.06, J12.1
SIPM_K7: J5.02, J13.1
SIPM_K8: J5.27, J14.1
SIPM_K9: J5.31, J15.1
SIPM_K10: J5.35, J16.1
SIPM_K11: J5.39, J17.1
SIPM_K12: J5.41, J18.1
SIPM_K13: J5.45, J19.1
SIPM_K14: J5.49, J20.1
SIPM_K15: J5.53, J21.1
SIPM_K16: J5.80, J22.1
SIPM_K17: J5.76, J23.1
SIPM_K18: J5.72, J24.1
SIPM_K19: J5.68, J25.1
SIPM_K20: J5.64, J26.1
SIPM_K21: J5.60, J27.1
SIPM_K22: J5.56, J28.1
SIPM_K23: J5.52, J29.1

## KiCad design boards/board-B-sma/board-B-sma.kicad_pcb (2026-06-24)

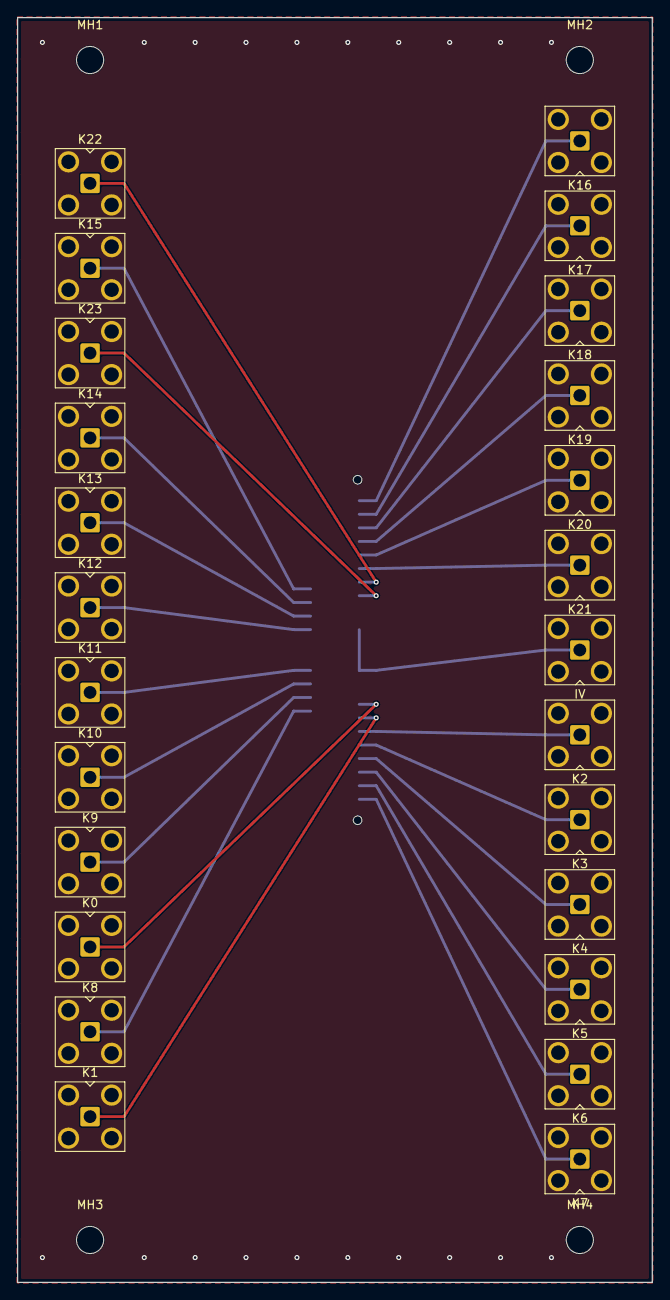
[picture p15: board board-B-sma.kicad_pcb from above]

Board: 4 copper layers, 74.8 x 149.1 mm, 30 parts (1 on the bottom side), 26 nets.

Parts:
IV: SMA_Amphenol_901-143_Horizontal
J5: SAMTEC_QSE-040-01-X-D-A
K0, K1, K2, K3, K4, K5, K6, K7, K8, K9, K10, K11, K12, K13, K14, K15, K16, K17, K18, K19, K20, K21, K22, K23: SMA_Amphenol_901-143_Horizontal
MH1, MH2, MH3, MH4: MountingHole_3.2mm_M3

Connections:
GNDA: IV.2, J5.01, J5.03, J5.04, J5.05, J5.07, J5.08, J5.09, J5.11, J5.12, J5.13, J5.15, J5.16, J5.17, J5.19, J5.20, J5.21, J5.23, J5.24, J5.25, J5.28, J5.29, J5.32, J5.33, J5.34, J5.36, J5.37, J5.38, J5.43, J5.44, J5.46, J5.47, J5.48, J5.50, J5.51, J5.54, J5.55, J5.57, J5.58, J5.59, J5.61, J5.62, J5.63, J5.65, J5.66, J5.67, J5.69, J5.70, J5.71, J5.73, J5.74, J5.75, J5.78, J5.G1, J5.G2, J5.G3, J5.G4, J5.G5, J5.G6, J5.G7, J5.G8, K0.2, K1.2, K2.2, K3.2, K4.2, K5.2, K6.2, K7.2, K8.2, K9.2, K10.2, K11.2, K12.2, K13.2, K14.2, K15.2, K16.2, K17.2, K18.2, K19.2, K20.2, K21.2, K22.2, K23.2
IV: IV.1, J5.40, J5.42
SIPM_K0: J5.30, K0.1
SIPM_K1: J5.26, K1.1
SIPM_K2: J5.22, K2.1
SIPM_K3: J5.18, K3.1
SIPM_K4: J5.14, K4.1
SIPM_K5: J5.10, K5.1
SIPM_K6: J5.06, K6.1
SIPM_K7: J5.02, K7.1
SIPM_K8: J5.27, K8.1
SIPM_K9: J5.31, K9.1
SIPM_K10: J5.35, K10.1
SIPM_K11: J5.39, K11.1
SIPM_K12: J5.41, K12.1
SIPM_K13: J5.45, K13.1
SIPM_K14: J5.49, K14.1
SIPM_K15: J5.53, K15.1
SIPM_K16: J5.80, K16.1
SIPM_K17: J5.76, K17.1
SIPM_K18: J5.72, K18.1
SIPM_K19: J5.68, K19.1
SIPM_K20: J5.64, K20.1
SIPM_K21: J5.60, K21.1
SIPM_K22: J5.56, K22.1
SIPM_K23: J5.52, K23.1

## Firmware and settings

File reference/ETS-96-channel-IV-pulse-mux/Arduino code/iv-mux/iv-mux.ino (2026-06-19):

/* Compile for Nano Every
 * Nano Every is found in Mega2560 boards
 */

/*
This file includes lines in preparation for the IV-mux motherboard v2.0
These are tagged with V2P0

*/
 
#include <avr/sleep.h>

// For Nano Every port definitions, see C:\Program Files (x86)\Arduino\hardware\tools\avr\avr\include\avr\iom4809.h

/*  Attempt to get it into low power state most of the time to reduce cooling requirements in vacuum
 *  - It didn't work
 *  - when trying to compile it later, the register accesses in the set_low_power routine failed 
 *  to compile in spite of setting AtMEGA328 emulation (although they had compiled previously)
 *  
 *  ... so the code is #defined out
*/
#define LOWPOWER_SLEEP 0
#define CTRL_C 3

// Macro to return number of elements in an array
#define COUNT_OF(x) ((sizeof(x) / sizeof(0 [x])) / ((size_t)(!(sizeof(x) % sizeof(0 [x])))))

// When undefined, compile for IV mux
// When defined, compile for IV-pulse mux
#define IVPULSEMUX

#ifdef IVPULSEMUX

// relay setup parameters
const int boardCount = 4;                           // how many boards are supported
const int channelsPerBoard = 24;                    // how many channels per board
const int maxChan = boardCount * channelsPerBoard;  // number of channels

// shift register (MIC5891) control pinout
int serPins[boardCount] = { 2, 3, 4, 5 };

// This is a hack to make the motherboard V1.0 work to address more than one daughterboard
// By mistake, a single IV_ON was designated on the microcontroller, and distributed to all boards
// instead of 4 of them, one distributed to each of the boards.
// Instead we used THERM1 - THERM4, and bridged each THERMn to the respective IV_ON pin, on the motherboard 
// (and also cut the IV_ON trace tying them all together)
int iv_on_pins[boardCount] = { A0, A1, A2, A3 };  

// V2P0 - new version for when these pins are connected
// Delete above version of iv_on_pins definition
//int iv_on_pins[boardCount] = { 6, 7, 8, 13 };  

const int SRCLK = 9;   // serial clock
const int RCLK = 10;   // strobe to active register
const int SRCLR = 11;  // asynchronous clear (active low)

//const int IV_ON = 13;  // DELETE ME
const int OE = 11;

const int BYPASS = 12;  // TEMPORARY - it shouldn't have been connected to pin 12!

#else

// relay pi parameters
const int boardCount = 6;                           // how many boards are supported
const int channelsPerBoard = 15;                    // how many channels per board
const int maxChan = boardCount * channelsPerBoard;  // number of channels
const int senseRelayBit = 15;                       // position of sense relay bit

// shift register (74HC595) control pinout
int serPins[boardCount] = { 2, 3, 4, 5, 6, 7 };
const int SRCLK = 9;   // serial clock
const int RCLK = 10;   // strobe to active register
const int SRCLR = 11;  // asynchronous clear (active low)

#endif

// For synchronization with IV curves using falling voltage transition
// Note: not on rev 1.0 PCB
const int SYNC_PULSE = 8;  // for sensing sync pulse - stealing last board select pin, for now

HardwareSerial *control;
HardwareSerial *debug;

const int inbuflen = 80;
char inbuf[inbuflen];
int charsInBuf;

/*
Look for the first port that receives 'g' and use it for control and debug
*/
void SetPort() {
  Serial.begin(9600);
  Serial1.begin(9600);

#define AUTO // auto select based on 'g'

#ifdef AUTO

  while(1)
  {
    int c;

    c = Serial.read();
    if ('g'== c) {
      control = debug = &Serial;
      debug->println("Serial chosen\n");
      break;
    }

    c = Serial1.read();
    if ('g'== c) {
      control = debug = &Serial1;
      debug->println("Serial1 chosen\n");
      break;
    }
  }

#else

// hard coded port
control = debug = &Serial1; // or &Serial

#endif

  control->print("MUX control interface\n\n");
}


void setup() {
  int i;

  //SetPort();

  for (i = 0; i < boardCount; i++) {
    pinMode(serPins[i], OUTPUT);
#ifdef IVPULSEMUX
    digitalWrite(iv_on_pins[i], LOW);
    pinMode(iv_on_pins[i], OUTPUT);
#endif
  }

// TEMPORARY
#ifdef IVPULSEMUX
  pinMode(BYPASS, OUTPUT);
  digitalWrite(BYPASS, LOW);
#endif

  pinMode(SRCLK, OUTPUT);
  pinMode(RCLK, OUTPUT);

#ifdef IVPULSEMUX
#else
  pinMode(SRCLR, OUTPUT);
#endif

  digitalWrite(SRCLK, LOW);
  digitalWrite(RCLK, LOW);

#ifdef IVPULSEMUX
  digitalWrite(OE, HIGH);  // high is inactive
  pinMode(OE, OUTPUT);
#else
  digitalWrite(SRCLR, HIGH);
#endif
  pinMode(SYNC_PULSE, INPUT_PULLUP);

  charsInBuf = 0;
  zeroState();
  writeState();

#ifdef IVPULSEMUX
  // after the shift registers are all initialized, enable the outputs
  digitalWrite(OE, LOW);  // low is active
#endif

#if LOWPOWER_SLEEP
  set_low_power();
#endif

  SetPort();

}

void loop() {
  int c;
#if LOWPOWER_SLEEP
  sleep();  // wake on UART interrupt
#endif
  // read a character
  c = control->read();
  if (-1 == c) return;

  // add it to the buffer, if there's room
  if (charsInBuf < COUNT_OF(inbuf))
    inbuf[charsInBuf++] = c;

#define DELIMS " \n\r"
  // separate into command and arguments
  char *command, *arg1, *arg2, *arg3;
  if (c == '\n' || c == '\r') {
    if (inbuf[charsInBuf - 1] == '\n') inbuf[--charsInBuf] = 0;
    if (inbuf[charsInBuf - 1] == '\r') inbuf[--charsInBuf] = 0;
    debug->print("Command: <");
    debug->print(inbuf);
    debug->println(">");
    command = strtok(inbuf, DELIMS);
    arg1 = strtok(NULL, DELIMS);
    arg2 = strtok(NULL, DELIMS);
    arg3 = strtok(NULL, DELIMS);
  } else
    return;

  int status = -1;

  // "a" activate command
  // activate just one channel, with its bias and sense relays
  if (0 == strcasecmp(command, "a")) {
    debug->println("Activating");
    int chan = atoi(arg1);
    status = channelActive(chan);
  }


// This bypass function only works on Rev 1
/* #ifdef IVPULSEMUX
  // "y" activate bYpass line if uppercase, deactivate if lowercase
  else if (0 == strcmp(command, "Y")) {
    debug->println("Activating bypass");
    digitalWrite(BYPASS, HIGH);
    status = 0;
  }

  else if (0 == strcmp(command, "y")) {
    debug->println("Deactivating bypass");
    digitalWrite(BYPASS, LOW);
    status = 0;
  }
#endif
 */
 
  // "t" temperature read command
  else if (0 == strcasecmp(command, "t")) {
    tempRead();
    status = 0;
  }

  // "s" sense relay command
  // set state of sense relay on board of specified channel: s c 1/0
  else if (0 == strcasecmp(command, "s")) {
    debug->println("Sense");
    int chan = atoi(arg1);
    int state = atoi(arg2);
    status = setSenseRelayState(chan, state);
#ifndef IVPULSEMUX
    writeState();
#endif
  }

  // "b" bias relay command
  // set state of bias  relay on specified board and channel: s c 1/0
  else if (0 == strcasecmp(command, "b")) {
    debug->println("Bias");
    int chan = atoi(arg1);
    int state = atoi(arg2);
    status = setBiasRelayState(chan, state);
    writeState();
  }

#ifndef IVPULSEMUX
  // "q" seQuence command
  // run through a range of channels, activating one at a time, for specified time (mS)
  else if (0 == strcasecmp(command, "q")) {
    debug->println("Sequence");
    int from = atoi(arg1);
    int to = atoi(arg2);
    unsigned long ms = atol(arg3);
    status = sequence(from, to, ms);
  }
#endif
  // "d" dump command
  // dump state
  else if (0 == strcasecmp(command, "d")) {
    debug->println("Dump");
    dumpState();
    status = 0;
  }

  // "w" write command
  // write state to relays
  else if (0 == strcasecmp(command, "w")) {
    debug->println("Write");
    writeState();
    status = 0;
  }

  // "z" zero state command
  // zero state
  else if (0 == strcasecmp(command, "z")) {
    debug->println("Zero");
    zeroState();
    writeState();
    status = 0;
  }

  // "p" powerdown command
  else if (0 == strcasecmp(command, "p")) {
    debug->println("Sleeping...");
    delay(1000);
    //debug->println("After ...");
    lpsleep();
    status = 0;
  }

  else if (*inbuf == 0) {
    printHelp();
    status = 0;  // no error on null command
  } else {
    printHelp();
  }

  if (status)
    debug->println("Error in command");
  else
    debug->println("Command complete");

  charsInBuf = 0;
}

#if LOWPOWER_SLEEP
// disable some unused peripherals
void set_low_power() {
  // Disable the ADC by setting the ADEN bit (bit 7)  of the
  // ADCSRA register to zero.
  ADCSRA &= ~0x80;  // B01111111;

  // Disable the analog comparator by setting the ACD bit
  // (bit 7) of the ACSR register to one.
  ACSR |= 0x80;  // B10000000;

  // Disable digital input buffers on all analog input pins
  // by setting bits 0-5 of the DIDR0 register to one.
  // Of course, only do this if you are not using the analog
  // inputs for your project.
  // DIDR0 = DIDR0 | B00111111; // not sure about this one
}

void sleep() {
  sleep_enable();
  set_sleep_mode(SLEEP_MODE_IDLE);
  sleep_cpu();
}

#endif

void lpsleep(){
  sleep_enable();
  set_sleep_mode(SLEEP_MODE_PWR_DOWN);
  sleep_cpu();
}

// An array of 16-bit words, one for each board (SER pin)
// active high
// bit 0 = ON0 .. bit 14 = ON14 .. bit 15 = SENSE_ON
#ifdef IVPULSEMUX
uint32_t outState[boardCount];
#else
uint16_t outState[boardCount];
#endif

int channelActive(int chan) {
  zeroState();
  if (setBiasRelayState(chan, true)) return -1;
  if (setSenseRelayState(chan, true)) return -1;
  writeState();
  return 0;
}

const unsigned long MIN_PULSE = 500;  // 500uS

int sequence(int from, int to, long mSdelay) {
  int i;
  bool abort = false;
  if (from < 1 || to < 1 || from > to)
    return -1;
  for (i = from; i <= to && !abort; i++) {

    debug->print("Activating ");
    debug->print(i);
    debug->print(", at ");
    debug->println(millis());

    if (channelActive(i)) return -1;  // activate channel; abort on error exit

    // for positive delay parameter, just delay
    if (mSdelay >= 0)
      delay(mSdelay);
    else {
      // for negative delay parameter, first find a (long enough) negative-going pulse on the sync line
      bool done = false;
      while (!done && !abort) {
        while (HIGH == digitalRead(SYNC_PULSE))
          if (abort |= control->read() == CTRL_C) break;
        unsigned long start = micros();
        while (LOW == digitalRead(SYNC_PULSE))
          if (abort |= control->read() == CTRL_C) break;
        unsigned long width = micros() - start;
        done = width >= MIN_PULSE;
        debug->print("Pulse width: ");
        debug->println(width);
      }

      delay(-mSdelay);
    }
  }
  zeroState();
  writeState();
  return 0;
}

void writeState() {
  int i, j;
#ifdef IVPULSEMUX
  uint32_t mask = 0x800000;
#else
  uint16_t mask = 0x8000;
#endif
  for (i = 0; mask; i++, mask >>= 1) {
    // set SER pins
    for (j = 0; j < boardCount; j++)
      digitalWrite(serPins[j], 0 != (outState[j] & mask) ? HIGH : LOW);

    // clock '595 shift register
    digitalWrite(SRCLK, HIGH);
    digitalWrite(SRCLK, LOW);
  }

  // update '595 output register
  digitalWrite(RCLK, HIGH);
  digitalWrite(RCLK, LOW);
}

void zeroState() {
  int i;
  for (i = 0; i < boardCount; i++) {
    outState[i] = 0;
    digitalWrite(iv_on_pins[i], LOW);
  }
}

void dumpState() {
  int i;
  for (i = 0; i < boardCount; i++)
    debug->println(outState[i], HEX);
}

int setBiasRelayState(uint16_t channel, bool enable) {
  if (channel < 1 || channel > maxChan) return -1;

  int board = (channel - 1) / channelsPerBoard;
  int chanOnBoard = (channel - 1) % channelsPerBoard;

  if (enable)
    bitSet(outState[board], chanOnBoard);
  else
    bitClear(outState[board], chanOnBoard);

  return 0;
}

int setSenseRelayState(uint16_t channel, bool enable) {
  if (channel < 1 || channel > maxChan) return -1;

  int board = (channel - 1) / channelsPerBoard;

#ifdef IVPULSEMUX

  digitalWrite(iv_on_pins[board], enable ? HIGH : LOW);

#else

  if (enable)
    bitSet(outState[board], senseRelayBit);
  else
    bitClear(outState[board], senseRelayBit);

#endif

  return 0;
}

void printHelp() {
  debug->println("a <channel>           : activate <channel>, clearing everything else and setting bias and sense");
  debug->println("s <channel> <state>   : set sense relay of <channel> to <state>");
  debug->println("t                     : print temperature (Kelvin) once per second until another character is received");
  debug->println("b <channel> <state>   : set bias relay of <channel> to <state>");
#ifndef IVPULSEMUX
  debug->println("q <from> <to> <delay> : activate channel from <from> to <to> in seQuence, with <delay> (mS) per step");
#endif
  debug->println("      (if <delay> < 0 wait for a trigger after each channel activation, and then wait - <delay> ");
  debug->println("d                     : dump state");
  debug->println("w                     : write state to relays");
#ifdef IVPULSEMUX
  debug->println("y                     : activate BYPASS if uppsercase, deactivate if lowercase");
#endif
  debug->println("z                     : zero state (and write to relays)");
}

// This is not tested / debugged yet
void tempRead() {

  // read internal temperature sensor
  while (control->read() == -1) {
    // Set VREF to 1.1V
    VREF.CTRLA = 0x11;  // 1V1 for ADC0, don't care for AC0
    VREF.CTRLB = 0x02;  // force enable of VREF for ADC0 (probably not needed)

    //ADC0.CTRLA = 0;       // disable until we're ready
    ADC0.CTRLC = 0x46;  // 128 prescaler, internal voltage reference, SAMPCAP = 1

    ADC0.MUXPOS = 0x1E;  // TEMPSENSE

    ADC0.CTRLD = 0xE0;     // maximum INITDLY
    ADC0.SAMPCTRL = 0x1f;  // maximum SAMPLEN

    ADC0.CTRLA = 1;  // enable ADC

    ADC0.COMMAND = 1;  // start conversion

    while (ADC0.COMMAND & 0x01)
      ;

    debug->println((ADC0.RES - SIGROW_TEMPSENSE1) * (SIGROW_TEMPSENSE0 / 256.0));
    delay(1000);
  }
}

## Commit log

2026-06-19 Initial commit: ETS per-channel SiPM breakout boards
    Passive per-channel breakouts (A=MCX, B=SMA, C=U.FL) that replace the broken
    iv-pulse-mux relay multiplexer; each fans 25 channels (24 SIPM_K + IV) from a
    QSE-040 (J5) socket to its own coax jack. All three boards DRC-clean (0/0) and
    fab-ready.
    - pinout.py is the single source of truth (QSE-040 J5 pin->net, from the upstream
    schematic netlist); boards are generated via tools/, never hand-placed.
    - Local datasheet-verified footprints; fab packages under boards/board-*/.
    - reference/ holds a de-gitted read-only snapshot of the upstream
    ETS-96-channel-IV-pulse-mux repo (provenance in reference/UPSTREAM.md).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
    [Channels.kicad_sch, bias-relay.kicad_sch, bias-relays-with-control.kicad_sch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]
2026-06-24 initial upload
    [MCX-J-P-X-ST-SM1.step, QSE-040-01-L-D-A.stp, SMP-MSLD-PCS-20.stp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]
2026-06-24 Add SMP Board D, mount J5 on back face, collect CAD assets + master BOM
    Boards / generator:
    - New Board D (SMP): Amphenol SMP-MSLD-PCS-20 vertical SMT jack; external signal
    tab routes like the other flat SMD jacks (no via-in-pad).
    - Mount J5 (QSE-040) on the back PCB face on all boards (detector plugs into the
    back, jacks on the front); finalize_board.py routes escapes on the QSE's actual
    copper layer, hopping layers only for the crossing fans.
    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
    [BOM.csv, SMP-MSLD-PCS-20.stp, U.FL_Hirose_U.FL-R-SMT-1_Vertical.step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]
2026-07-11 Finalize Board A (MCX) for purchase: confirm MPNs, add full order BOM
    - MCX-J-P-H-ST-SM1 confirmed orderable (DigiKey SAM10608-ND, live-verified
    2026-07-11); correct SM1 rev C drawing added to docs/datasheets/
    - QSE-040-01-L-D-A = DigiKey SAM8124-ND (plain suffix; never -RT1)
    - make_bom.py PARTS carries the DK PNs; all 4 board BOM CSVs + fab zips regenerated
    - docs/BOM.md: Digi-Key column + Purchase order section (110x MCX, 5x QSE,
    5x PCB controlled-impedance quotes JLCPCB/PCBWay, quick-add block)
    - docs/BOM.csv: Digi-Key column + SM1 datasheet reference
    - CLAUDE.md status: purchase-ready; MCX open item closed
    [BOM.csv, board-A-mcx-bom.csv, board-B-sma-bom.csv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]
2026-07-11 Remove MT1 through-hole MCX drawing; align symbol/BOM refs to verified SM1
    The SM1 rev C print (Samtec_MCX-J-P-X-ST-SM1.pdf) is verified byte-identical
    to the live Samtec source and confirms MCX STRAIGHT SMT JACK 50 OHM, -H heavy
    gold, tray packaging. The MT1 drawing was the mixed-technology (through-hole
    leg) family - a different part not used on any board - so it is removed.
    - rename reference symbol MCX-J-P-X-ST-MT1 -> -SM1, repoint Datasheet,
    PARTREV B -> C, fill description (Footprint field already pointed at SM1)
    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
    [BOM.csv]
2026-07-11 Add purchase handover package (order/): JLCPCB wizard + DigiKey BOM
    - order/board-A-mcx-jlcpcb.zip: clean gerbers+drill upload for the JLCPCB
    instant-quote wizard (28 files, no CSVs)
    - order/digikey-bom-connectors.csv: myLists-uploadable connector BOM at
    4-board qty + 20% spares (120x SAM10608-ND, 5x SAM8124-ND)
    - order/README.md: engineer-facing walkthrough - wizard field table,
    impedance remark text, substitution rules, checklist (~$625 total)
    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
    [digikey-bom-connectors.csv]
2026-07-11 BOM: add 4x SMA-to-TRB triax adapter (DK 1097-1372-ND) for IV out
    Cinch 3-0347-9, $72.41 ea, 1 per board. Added to docs/BOM.md purchase
    order, order/README.md, and the DigiKey upload CSV / quick-add blocks;
    totals updated ($625 -> ~$915).
    [digikey-bom-connectors.csv]
2026-07-11 Add generated reference schematic for human review (docs/schematic/)
    tools/gen_schematic.py builds a single-sheet A3 schematic from pinout.py
    (the same single source of truth the boards are generated from): J5 as an
    88-pin symbol with pin names = nets, 25 jacks with board refs (K0-K23, IV),
    net-label connectivity, THERM4/5 no-connect.
    Verification: ERC 0 errors; exported netlist machine-verified identical to
    pinout.py (25 signals, GNDA 85/85, THERM unconnected). 26 warning-level
    "lib nickname" notices are inherent to a standalone sheet with embedded
    symbols. PDF exported alongside for review without KiCad.
    Docs updated: CLAUDE.md (layout, open items), README.md (fab checklist),
    session-rep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
    [ets-breakout.kicad_sch]
2026-07-15 Board A: through-hole MCX + 8/16 planar FreeRouting autoroute (JLC)
    Re-lay-out Board A to eliminate the connector-crossing tracks and the
    per-jack signal vias the reviewer flagged:
    - Jack SMD -> THROUGH-HOLE: Samtec MCX-J-P-H-ST-TH1 (DK SAM8944-ND). The
    plated signal pin reaches every layer, so the QSE B.Cu escape lands on
    it with no face-change via. New datasheet-verified footprint + drawing.
    - Placement 12/12 -> 8/16 planar: each jack sits on the edge matching its
    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
    [BOM.csv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]
2026-07-17 update after engineering review
    [BOM.csv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]
2026-07-17 Board A: engineer-review pass — balanced layout, J-designators, LCSC assembly
    Address the engineer's review of Board A (MCX):
    - Placement balanced 8/16 -> ~12/13, jacks ordered by QSE pin so native
    routes are straight; the 4 opposite-side channels wrap the connector
    ends on B.Cu (2 per corner) -> still 0 signal vias, 0 crossings, DRC 0/0.
    Board shrank 75x157 -> 75x125 mm. Old 8/16 kept as gen_board SPLIT="planar".
    - Designators K->J: jacks are connectors, not relays. Socket stays J5
    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
    [BOM.csv, board-A-mcx-bom.csv]
2026-07-17 Clean up routing and MCX connector placement.
    Adjust silkscreen circuit designator size and placement.
    [board-A-mcx.kicad_pcb]
2026-07-17 changes to project file, of unknown provenance, done by KiCAD
2026-07-18 Regenerate fab from engineer's board; gen_board reproduces his wrap swap
    The engineer hand-cleaned Board A's routing + MCX placement in KiCad
    (697d0fa) but didn't regenerate the fab. Reviewed: his only placement
    change was swapping each wrap pair (top K17<->K16, bottom K7<->K6) so the
    two arcs per corner nest without crossing; re-routed, still 0 signal vias,
    all B.Cu, DRC 0/0, netclass 0.325 intact (GUI didn't flatten .kicad_pro).
    - Fab regenerated from his board (gerbers/drill/pos/BOM/zips/routed-top);
    his .kicad_pcb preserved byte-for-byte.
    - gen_board.py now places wrapped (spilled) channels in reversed pin order
    (a corner wrap reverses the fan sense) -> regenerates his exact placeme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
    [board-A-mcx-B_Courtyard.gbr, board-A-mcx-B_Cu.gbl, board-A-mcx-B_Fab.gbr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]
2026-07-20 order: add JLCPCB assembly BOM (LCSC) + CPL; new tools/make_jlc.py
    The order/ folder had only DigiKey hand-solder files, so a JLCPCB assembly
    order had no pick-and-place and JLC read the DigiKey BOM as DigiKey sourcing.
    Add the two files JLC's assembly step needs:
    - board-A-mcx-jlc-cpl.csv: pick-and-place re-headed to JLC's columns
    (Designator, Mid X, Mid Y, Layer, Rotation). KiCad's raw fab pos.csv is
    rejected on its headers; coordinates already Y-up and gerber-aligned
    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
    [board-A-mcx-jlc-bom.csv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]

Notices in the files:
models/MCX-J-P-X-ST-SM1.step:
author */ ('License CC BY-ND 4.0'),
